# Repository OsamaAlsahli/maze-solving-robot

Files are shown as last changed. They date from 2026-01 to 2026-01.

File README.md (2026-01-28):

# Maze-Solving Robot 🤖

Autonomous differential-drive robot that navigates an unknown maze using the **Bug2 algorithm**, records its path, and returns to the starting position.

**University of York | ELE00098H Robotics Design and Construction | January 2026**





---

## 🎯 Project Overview

This project was developed as part of the ELE00098H Robotics module assessment. The robot must:

1. **Navigate** from START to FINISH through an unknown maze
2. **Avoid obstacles** using real-time sensor feedback
3. **Record** its path during exploration
4. **Return** to start using the recorded path

The maze is approximately 200cm long with corridor widths of 29-34cm.

---

## ✅ Features

- **Bug2 Navigation Algorithm** - Modified for sensor-based decision making
- **Path Recording** - Every move stored for efficient return journey
- **5 Distance Sensors** - Ultrasonic (front) + 4x IR (left, right, front-left, front-right)
- **Encoder Odometry** - Tracks distance with straight-line correction
- **Obstacle Avoidance** - Real-time diagonal obstacle detection and avoidance maneuvers
- **Dual Speed Modes** - Slow exploration (0.3) and fast return (0.6)

---

## 🔧 Hardware

| Component | Description |
|---|---|
| **Microcontroller** | Arduino Nano 33 BLE |
| **Motor Driver** | TB6612FNG Dual H-Bridge |
| **Motors** | 2x Micro metal gear motors with quadrature encoders |
| **Front Sensor** | HC-SR04 Ultrasonic (long range) |
| **Side Sensors** | 4x Sharp IR distance sensors via TCA9548A I2C multiplexer |
| **Power** | Li-Po battery pack |
| **Chassis** | Custom 3D printed / laser cut design |

### Sensor Configuration

```
        [Front US]
           ↑
    [FL]   |   [FR]
      \    |    /
       \   |   /
  [L] ← [ROBOT] → [R]
```

- **Front (US):** Long-range obstacle detection (up to 400cm)
- **Left/Right (IR):** Wall detection for corridor navigation
- **Front-Left/Front-Right (IR):** Diagonal obstacle detection at 45°

---

## 🧠 Algorithm

### Bug2 Navigation (Modified)

The classic Bug2 algorithm tries to move directly toward a goal, and when blocked, follows the obstacle boundary until it can resume direct travel. Our modification uses sensor data for smarter turn decisions.

#### Decision Logic

```
┌─────────────────────────────────────────────────────────────┐
│                      MAIN LOOP                               │
├─────────────────────────────────────────────────────────────┤
│                                                              │
│  1. IF facing NORTH and front clear:                         │
│     → Move forward, track north progress                     │
│     → Check if finish reached (≥195cm north)                 │
│                                                              │
│  2. IF facing EAST and left opens up:                        │
│     → Turn left (toward north)                               │
│     → If north blocked, turn back + move forward             │
│                                                              │
│  3. IF facing WEST and right opens up:                       │
│     → Turn right (toward north)                              │
│     → If north blocked, turn back + move forward             │
│                                                              │
│  4. IF facing SOUTH:                                         │
│     → Turn toward any open direction                         │
│                                                              │
│  5. IF front blocked:                                        │
│     → Compare left vs right sensor readings                  │
│     → Turn toward MORE OPEN direction                        │
│     → Move forward short to clear corner                     │
│                                                              │
│  6. ELSE (front clear, not facing north):                    │
│     → Move forward                                           │
│                                                              │
└─────────────────────────────────────────────────────────────┘
```

### Path Recording & Return

Every move is recorded as one of five types:

| Move Type | Description |
|---|---|
| `M_FORWARD` | Forward 20cm |
| `M_FORWARD_SHORT` | Forward 10cm |
| `M_RIGHT` | Turn right 90° |
| `M_LEFT` | Turn left 90° |
| `M_AWAY` | Turn around 180° |

**Return Algorithm:**
1. Turn 180° to face start
2. Replay moves in reverse order
3. Invert turns: `LEFT ↔ RIGHT`
4. Execute at higher speed (0.7 vs 0.3)

---

## 🐛 Challenges & Solutions

### 1. Ultrasonic Sensor Noise

**Problem:** Random low readings (0.5-2cm) caused false wall detections, stopping the robot in clear corridors.

**Symptoms:**
```
B:0 F:32.15 L:14.5 R:13.2
Action: Moving Forward
North progress: 60

B:0 F:0.52 L:14.1 R:13.7
Wall stop at: 0.52          ← False detection!
```

**Solution:** Two-part filtering:
```cpp
if(f_val < front_closed && f_val > 7){  // Ignore readings < 7cm
  wall_cnt++;
  if(wall_cnt >= 5){                     // Require 5 consecutive readings
    stop();
  }
} else {
  wall_cnt = 0;                          // Reset on clean reading
}
```

### 2. Infinite Loop at Junctions

**Problem:** Robot got stuck turning back and forth at junctions without moving forward.

**Symptoms:**
```
B:0 F:0.66 → Turn Right
B:1 → Turn Left back to North  
B:0 F:0.97 → Turn Right
[repeats forever]
```

**Solution:** Added forward movement after turn-back sequences:
```cpp
if(check < 10){
  turn_right();           // North blocked, turn back
  go_forward_short();     // CRITICAL: Move away from junction
}
```

### 3. Suboptimal Path Selection

**Problem:** Fixed right-turn preference caused robot to take longer routes.

**Solution:** Sensor-based direction choice:
```cpp
if(l_val > 15 && r_val > 15){
  // Both sides open - choose MORE OPEN direction
  if(r_val > l_val) turn_right();
  else turn_left();
}
```

---

## 📁 Project Structure

```
maze-solving-robot/
├── README.md
├── src/
│   ├── working/                    # Final working implementation
│   │   ├── RoboBug2_working_return.ino
│   │   ├── RoboHW.cpp             # Hardware abstraction
│   │   ├── RoboHW.h
│   │   ├── RoboNav.cpp            # Navigation functions
│   │   ├── RoboNav.h
│   │   ├── RoboMap.cpp            # Bug2 algorithm & path recording
│   │   └── RoboMap.h
│   │
│   └── experimental/               # Alternative approaches (not used)
│       ├── grid-based/            # Grid mapping approach
│       │   ├── GridHW.cpp/h
│       │   ├── GridNav.cpp/h
│       │   └── GridMap.cpp/h
│       └── node-based/            # Topological mapping approach
│           ├── NodesHW.cpp/h
│           ├── NodesNav.cpp/h
│           └── NodesMap.cpp/h
│
├── docs/
│   ├── images/
│   └── presentation.pdf
│
└── hardware/
    └── CAD/
```

---

## 🔬 Experimental Approaches

### Grid-Based Mapping

**Concept:** Divide maze into discrete cells, track visited/blocked/unknown states, use depth-first search with backtracking.

**Why it failed:** 
- Required precise odometry that our hardware couldn't reliably provide
- Small positioning errors accumulated over time
- Robot lost track of its actual grid position

**What we learned:** Map-based approaches need accurate localization.

### Node-Based (Topological) Mapping

**Concept:** Represent maze as a graph where junctions are nodes and corridors are edges. No precise positioning needed.

**Why it failed:**
- Junction detection was unreliable
- Sometimes detected false junctions in corridors
- Sometimes missed real junctions

**What we learned:** Junction detection requires careful tuning and possibly additional sensors.

### Why Bug2 Worked

- **Reactive** - Responds to current sensor readings, not accumulated position
- **No map required** - Doesn't need to remember maze structure
- **Robust to errors** - Odometry drift doesn't compound
- **Simple** - Fewer failure modes

---

## 🚀 Building & Running

### Prerequisites

- Arduino IDE 2.x
- Arduino Mbed OS Nano Boards package

### Installation

1. Clone this repository:
   ```bash
   git clone https://github.com/OsamaAlsahli/maze-solving-robot.git
   ```

2. Open `src/working/RoboBug2_working_return.ino` in Arduino IDE

3. Select board: **Arduino Nano 33 BLE**

4. Upload to robot

5. Open Serial Monitor (9600 baud) to view debug output

### Serial Output

```
==========BUG2 TRIAL==========
B:0 F:45.23 L:14.2 R:13.8
Action: Moving Forward
North progress: 20

B:0 F:38.67 L:13.9 R:14.1
Action: Moving Forward
North progress: 40

...

=== REACHED FINISH LINE! ===
=== RECORDED PATH ===
Total moves: 23
0: FWD
1: FWD
2: RIGHT
...
=== RETURNING TO START ===
Return step 1/23
...
=== BACK AT START ===
COMPLETE!
```

---

## 📊 Results

| Metric | Value |
|---|---|
| Maze Length | ~200cm |
| Completion Rate | ✅ 80% |
| Average Solve Time | ~45 seconds |
| Return Journey | ✅ Working |
| Unknown Maze Test | ⚠️ Partial Completion |
| Overall Assessment | ✅ Passed ("flying colours") |
---

## 📚 Lessons Learned

1. **Start simple** - Reactive algorithms often outperform complex map-based approaches
2. **Sensor filtering is critical** - Real sensors are noisy; always filter
3. **Test incrementally** - Debug each component before integration
4. **Log everything** - Serial output saved hours of debugging
5. **Have fallback plans** - We tried 3 approaches before finding one that worked

---

## 🎥 Demo

[Demo Video](https://drive.google.com/file/d/1f_MGWNPrCgAjsQp2QtPEfJgEfQqXqQkQ/view?usp=sharing)
---

## 👤 Author

**Osama Alsahli**  
BEng (Hons) Engineering  
University of York

- GitHub: [@OsamaAlsahli](https://github.com/OsamaAlsahli)
- Linkedin: [Linkedin](https://www.linkedin.com/in/osama-alsahli-325080317/)
- email: ossamaalsahli@gmail.com

---

## 📄 License

This project is licensed under the MIT License - see the [LICENSE](LICENSE) file for details.

---

## 🙏 Acknowledgments

- University of York ELE00098H teaching team
- Lab technicians for hardware support and guidance
- Anthropic Claude for debugging assistance

---

*This project was completed as part of the ELE00098H Robotics Design and Construction module, contributing 100% of the module grade.*

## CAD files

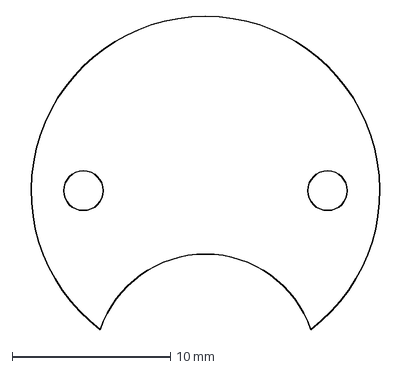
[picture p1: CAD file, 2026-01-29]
CAD/dxf_files/Caster Spacer 3mm.dxf
23.9 x 19.8 mm

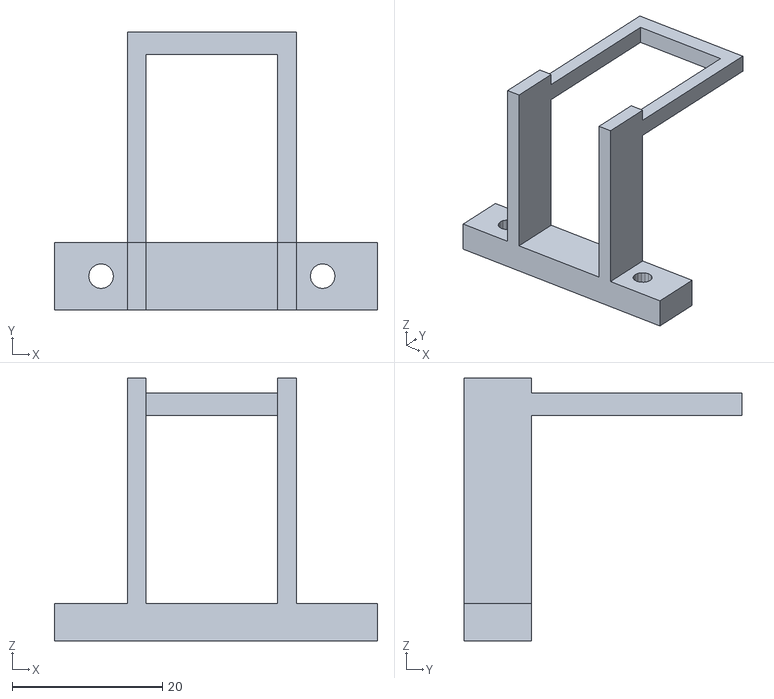
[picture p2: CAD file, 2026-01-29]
CAD/stl_files/Batteryholder1.stl
43.0 x 37.0 x 35.0

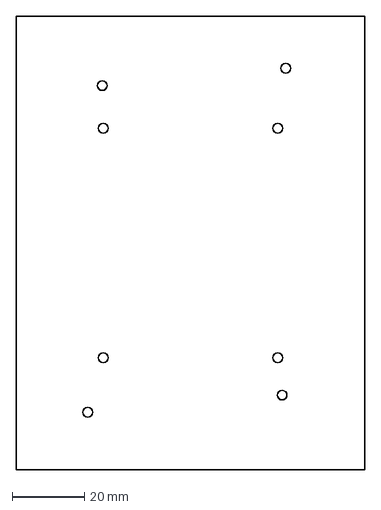
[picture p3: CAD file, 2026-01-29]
CAD/dxf_files/holder_1.dxf
96.5 x 125.5 mm

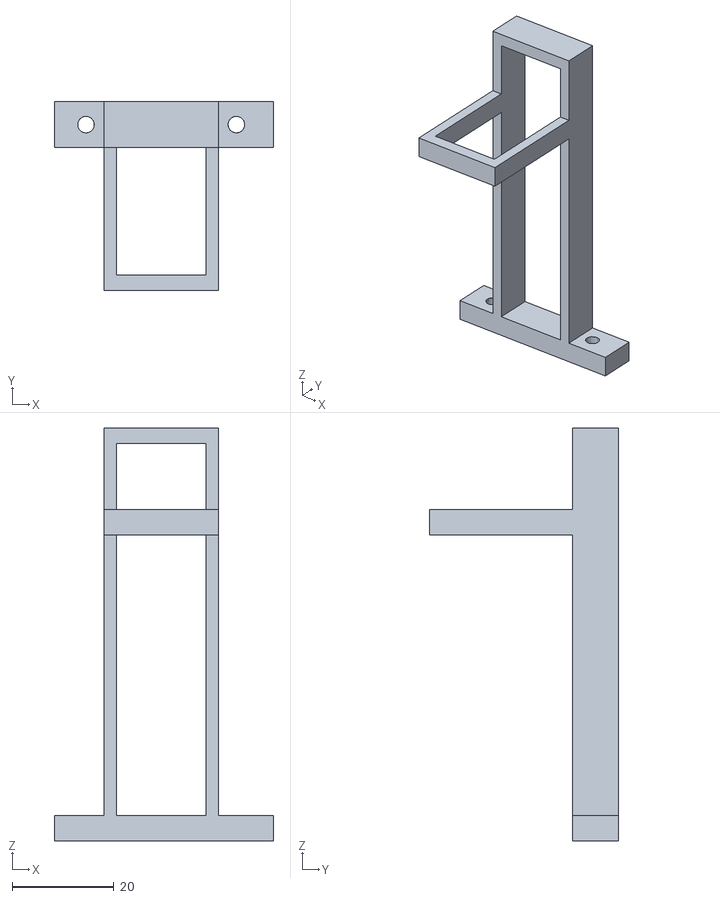
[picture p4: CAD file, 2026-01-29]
CAD/stl_files/Batteryholder2.stl
43.0 x 37.0 x 81.0

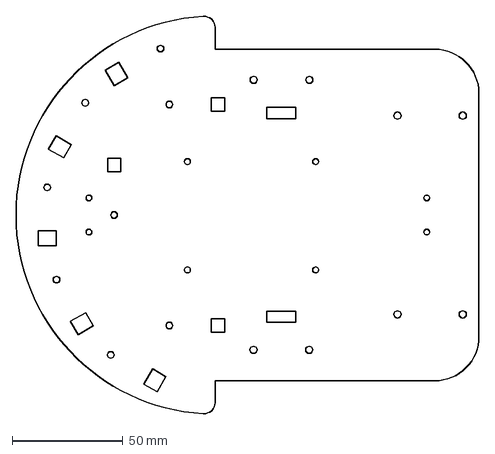
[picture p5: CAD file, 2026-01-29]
CAD/dxf_files/Base_plate_v1_Exam.dxf
209.4 x 179.9 mm

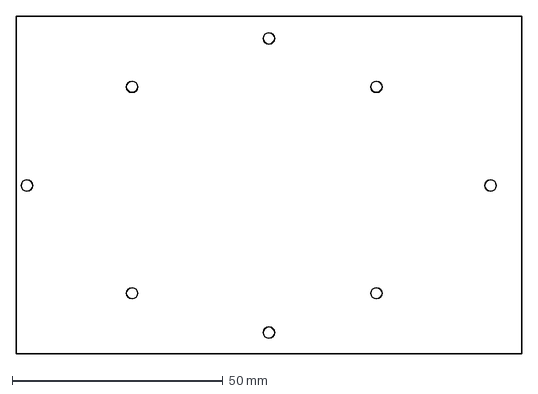
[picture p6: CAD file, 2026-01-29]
CAD/dxf_files/plate.dxf
120.0 x 80.0 mm

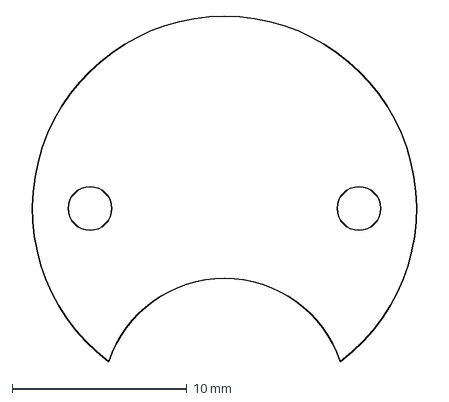
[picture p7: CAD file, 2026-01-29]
CAD/dxf_files/Caster Spacer 5mm.dxf
23.9 x 19.8 mm

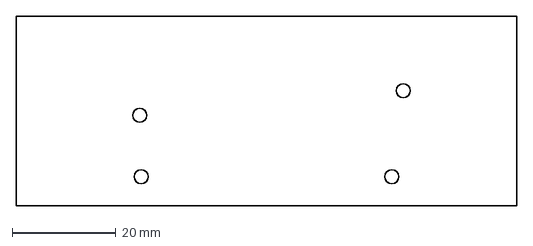
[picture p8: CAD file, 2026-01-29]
CAD/dxf_files/holder_2.dxf
96.5 x 36.6 mm

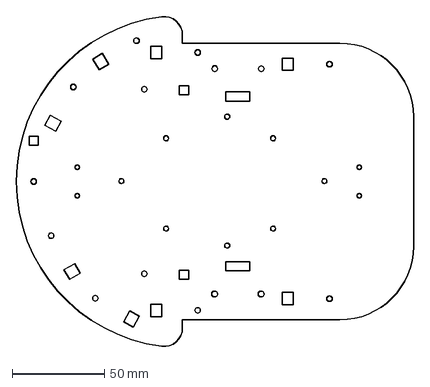
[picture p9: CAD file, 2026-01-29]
CAD/dxf_files/Base_plate_v3.dxf
215.2 x 179.3 mm

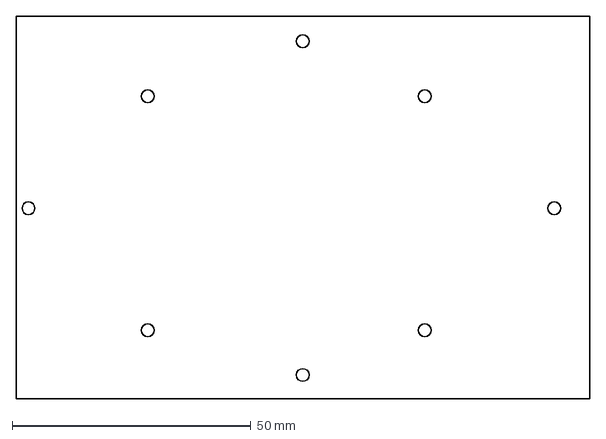
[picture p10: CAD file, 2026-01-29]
CAD/dxf_files/topplate.dxf
120.0 x 80.0 mm

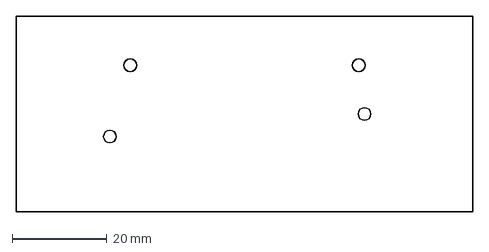
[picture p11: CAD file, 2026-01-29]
CAD/dxf_files/holder_3.dxf
96.5 x 41.3 mm

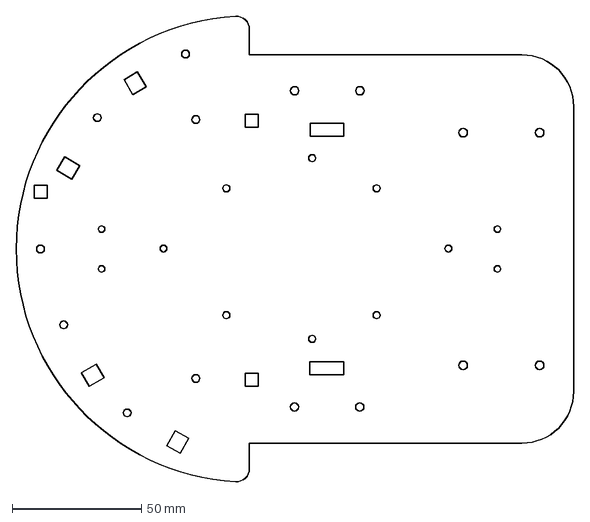
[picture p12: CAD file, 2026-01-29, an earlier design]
CAD/dxf_files/Base_plate_v2.dxf
215.2 x 179.9 mm

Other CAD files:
CAD/0.75in Ball Caster (Pololu).ipt
CAD/0.75in Ball Caster (Pololu)_MIR.ipt
CAD/Battery.ipt
CAD/BatteryHolder.ipt
CAD/BatteryHolder_MIR.ipt
CAD/Batteryholder1.ipt
CAD/Batteryholder2.ipt
CAD/Caster Spacer 1,7mm.ipt
CAD/Caster Spacer 3,1mm.ipt
CAD/Caster Spacer 3mm.ipt
CAD/Caster Spacer 5mm.ipt
CAD/M2.5 Hex Spacer 5mm.ipt
CAD/MotorHolder.ipt
CAD/MotorHolder_MIR.ipt
CAD/MotorHolder_MIR1.ipt
CAD/Pololu_MMG_Motor.ipt
CAD/base_plate.ipt
CAD/battery2.ipt
CAD/robot_assembly.iam
CAD/top_plate.ipt
CAD/topplate_v2.ipt
CAD/wheel.ipt

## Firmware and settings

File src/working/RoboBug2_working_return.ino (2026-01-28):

/*
 * RoboBug2_working_return.ino - Main Robot Controller
 * 
 * Maze-Solving Robot for ELE00098H Assessment
 * University of York - School of Physics, Engineering and Technology
 * 
 * =============================================================================
 * PROJECT OVERVIEW
 * =============================================================================
 * 
 * This robot navigates a maze from START to FINISH and back using:
 *   - Bug navigation algorithm (modified for sensor-based decisions)
 *   - Path recording for efficient return journey
 *   - Multiple sensors for obstacle detection and avoidance
 * 
 * =============================================================================
 * HARDWARE CONFIGURATION
 * =============================================================================
 * 
 * Microcontroller: Arduino Nano 33 BLE
 * Motor Driver:    TB6612FNG dual H-bridge
 * Motors:          2x micro metal gear motors with encoders
 * 
 * Sensors:
 *   - 1x HC-SR04 ultrasonic (front, long range)
 *   - 4x Sharp IR distance sensors via I2C multiplexer:
 *     - Left (90°)
 *     - Right (90°)
 *     - Front-Left (45°)
 *     - Front-Right (45°)
 * 
 * =============================================================================
 * ALGORITHM SUMMARY
 * =============================================================================
 * 
 * Phase 3 - Maze Solving (bug2_try):
 * 1. Primary goal: Travel north toward finish line
 * 2. When blocked: Choose direction based on sensor readings
 * 3. Track total north progress to detect finish
 * 4. Record every move for return journey
 * 
 * Phase 4 - Return Journey (return_to_start):
 * 1. Turn 180° to face start
 * 2. Replay recorded moves in reverse order
 * 3. Invert turns (LEFT↔RIGHT)
 * 4. Travel at higher speed (0.6 vs 0.3)
 * 
 * =============================================================================
 * CODE ORGANIZATION
 * =============================================================================
 * 
 * RoboHW.h/cpp   - Hardware abstraction (motors, sensors, encoders)
 * RoboNav.h/cpp  - Navigation functions (motion commands, obstacle avoidance)
 * RoboMap.h/cpp  - Maze solving algorithm and path recording
 * 
 * Author: fwm509
 * Module: ELE00098H Robotics Design and Construction
 * Date: January 2026
 */

#include <mbed.h>
#include <cmath>

#include "RoboHW.h"
#include "RoboNav.h"
#include "RoboMap.h"

using namespace mbed;

//=============================================================================
// SETUP - Run once at startup
//=============================================================================

/**
 * Initialize robot hardware and prepare for maze solving
 */
void setup() {
  // Initialize serial communication for debugging (9600 baud)
  Serial.begin(9600);
  
  // Initialize hardware (motors, encoders, sensors)
  hw_init();
  
  // Wait 2 seconds for robot to be placed and user to step back
  // Also allows sensors to stabilize
  wait_us(2000000);
  
  // Initialize state flags
  maze_finished = false;
  path_len = 0;
  
  Serial.println("=================================");
  Serial.println("  MAZE SOLVING ROBOT");
  Serial.println("  Ready to start!");
  Serial.println("=================================");
}

//=============================================================================
// MAIN LOOP - Runs continuously
//=============================================================================

/**
 * Main control loop
 * 
 * State machine:
 * 1. maze_finished == false: Run bug2_try() to solve maze
 * 2. maze_finished == true:  Execute return journey, then stop
 */
void loop() {
  if(!maze_finished) {
    //=========================================================================
    // PHASE 3: SOLVE THE MAZE
    //=========================================================================
    // Run Bug2 algorithm to navigate from START to FINISH
    // This function records all moves and sets maze_finished = true when done
    bug2_try();
    
  } else {
    //=========================================================================
    // PHASE 4: RETURN TO START
    //=========================================================================
    
    // Print the recorded path for demonstration
    print_path();
    
    // Wait 3 seconds at finish line (for assessment demonstration)
    Serial.println("Waiting 3 seconds before return...");
    wait_us(3000000);
    
    // Execute return journey using recorded path
    return_to_start();
    
    // Mission complete - stop and report
    while(true) {
      stop();
      Serial.println("=================================");
      Serial.println("  MISSION COMPLETE!");
      Serial.println("  Robot has returned to start.");
      Serial.println("=================================");
      wait_us(5000000);           // Print status every 5 seconds
    }
  }
}

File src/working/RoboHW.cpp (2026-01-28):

/*
 * RoboHW.cpp - Hardware Abstraction Layer Implementation
 * 
 * This module implements low-level hardware control for the maze-solving robot.
 * It provides motor control with encoder feedback, and sensor reading functions.
 * 
 * Key Features:
 *   - Differential drive control with PWM
 *   - Quadrature encoder counting via interrupts
 *   - Proportional straight-line correction
 *   - Ultrasonic and IR sensor interfaces via I2C multiplexer
 * 
 * Author: fwm509
 * Module: ELE00098H Robotics Design and Construction
 * Date: January 2026
 */

#include "RoboHW.h"
#include "RoboNav.h"
#include "RoboMap.h"
#include <cmath>

using namespace mbed;

//=============================================================================
// HARDWARE PIN DEFINITIONS
//=============================================================================

// Motor A (Left) - PWM speed control and direction
PwmOut pwma(P0_27);               // PWM output for left motor speed
DigitalOut dira(P0_4);            // Direction control for left motor

// Motor B (Right) - PWM speed control and direction
PwmOut pwmb(P1_2);                // PWM output for right motor speed
DigitalOut dirb(P0_5);            // Direction control for right motor

// Encoder inputs - Using interrupts for accurate counting
InterruptIn tica(P1_11);          // Left motor encoder channel A
InterruptIn ticb(P1_12);          // Right motor encoder channel A

// Ultrasonic sensor - Single pin for trigger and echo
DigitalInOut us_front(P0_23);     // HC-SR04 ultrasonic sensor

// Timer for ultrasonic pulse measurement
Timer us_t;

// I2C bus for IR sensors (via multiplexer)
I2C i2c(P0_31, P0_2);             // SDA, SCL pins

//=============================================================================
// GLOBAL VARIABLES
//=============================================================================

// Encoder counts - volatile because modified in ISR
volatile long int enca = 0;       // Left encoder tick count
volatile long int encb = 0;       // Right encoder tick count

// Motion state flags
bool mvng_frwrd = false;          // Currently moving forward
bool trnng = false;               // Currently turning

// Motion control variables
long int tt = 0;                  // Target tick count for motion
float lcs = 0.0;                  // Left corrected speed
float rcs = 0.0;                  // Right corrected speed
float l_speed = 0;                // Left motor speed setting
float r_speed = 0;                // Right motor speed setting
int l_dir = +1;                   // Left motor direction
int r_dir = +1;                   // Right motor direction

// Odometry constants and variables
float dpt = 0.048;                // Distance per encoder tick (cm)
                                  // Calculated from wheel circumference / encoder CPR
float disa = 0;                   // Distance traveled by left wheel
float disb = 0;                   // Distance traveled by right wheel
float speed;                      // Current speed setting
float k = 0.025;                  // Proportional gain for straight-line correction
float tpd = 3.15;                 // Encoder ticks per degree of rotation
                                  // Calibrated for robot's wheel base

float diff = 0;                   // Encoder difference (for correction)
float us_r = 0;                   // Last ultrasonic reading

//=============================================================================
// ENCODER INTERRUPT SERVICE ROUTINES
//=============================================================================

/**
 * Left encoder ISR
 * Called on rising edge of encoder signal
 * Increments or decrements count based on direction
 */
void l_cnt() {
  enca = enca + l_dir;
}

/**
 * Right encoder ISR
 * Called on rising edge of encoder signal
 * Increments or decrements count based on direction
 */
void r_cnt() {
  encb = encb + r_dir;
}

//=============================================================================
// ODOMETRY FUNCTIONS
//=============================================================================

/**
 * Calculate distance traveled by each wheel
 * Converts encoder ticks to centimeters
 */
void distance() {
  disa = abs(enca) * dpt;
  disb = abs(encb) * dpt;
}

//=============================================================================
// MOTOR CONTROL FUNCTIONS
//=============================================================================

/**
 * Set individual wheel speeds with direction control
 * 
 * @param l_speed Left motor speed (-1.0 to 1.0)
 * @param r_speed Right motor speed (-1.0 to 1.0)
 * 
 * Positive values = forward, negative = reverse
 * Sets direction pins and PWM duty cycle
 */
void wheels(float l_speed, float r_speed) {
  // Left motor direction control
  if (l_speed > 0) {
    dira = 1;                     // Forward direction
    l_dir = +1;                   // Encoder counts up
  } else if (l_speed < 0) {
    dira = 0;                     // Reverse direction
    l_dir = -1;                   // Encoder counts down
  } else {
    l_dir = 0;                    // Stopped
  }
  
  // Right motor direction control
  if (r_speed > 0) {
    dirb = 1;                     // Forward direction
    r_dir = +1;                   // Encoder counts up
  } else if (r_speed < 0) {
    dirb = 0;                     // Reverse direction
    r_dir = -1;                   // Encoder counts down
  } else {
    r_dir = 0;                    // Stopped
  }
  
  // Set PWM duty cycle (absolute value for speed magnitude)
  pwma.write(fabs(l_speed));
  pwmb.write(fabs(r_speed));
}

/**
 * Emergency stop - immediately halt both motors
 * Also clears motion state flags
 */
void stop() {
  wheels(0, 0);
  mvng_frwrd = false;
  trnng = false;
}

//=============================================================================
// MOTION PRIMITIVE FUNCTIONS
//=============================================================================

/**
 * Initiate forward motion for a specified distance
 * 
 * @param dis Distance to travel in centimeters
 * @param spd Speed (0.0 to 1.0)
 * 
 * This is non-blocking - it sets up the motion parameters
 * Use wait_until_done() to block until motion completes
 */
void move_forward(float dis, float spd) {
  enca = 0;                       // Reset encoder counts
  encb = 0;
  tt = dis / dpt;                 // Calculate target ticks
  speed = spd;                    // Store speed for correction
  mvng_frwrd = true;              // Set motion flag
}

/**
 * Initiate backward motion for a specified distance
 * 
 * @param dis Distance to travel in centimeters
 * @param spd Speed (0.0 to 1.0)
 */
void move_back(float dis, float spd) {
  enca = 0;
  encb = 0;
  tt = dis / dpt;
  speed = -spd;                   // Negative speed for reverse
  mvng_frwrd = true;
}
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
